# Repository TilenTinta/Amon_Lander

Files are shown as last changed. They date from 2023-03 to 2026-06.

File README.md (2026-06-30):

# Amon Lander Project

**Project Status:** In Progress

**Short description:** An open‑source EDF‑hovering lander/hopper inspired by **Sprite** (BPS.space)

> Part of the Amon Lander project:
>
> - **Amon Board** — flight controller hardware & firmware  
>   https://github.com/TilenTinta/Amon_Board
> - **Amon Link** — PC - drone RF bridge (PCB & firmware)  
>   https://github.com/TilenTinta/Amon_Link
> - **Amon Ground Control** — desktop GCS for telemetry & control  
>   https://github.com/TilenTinta/Amon_GroundControl_Software

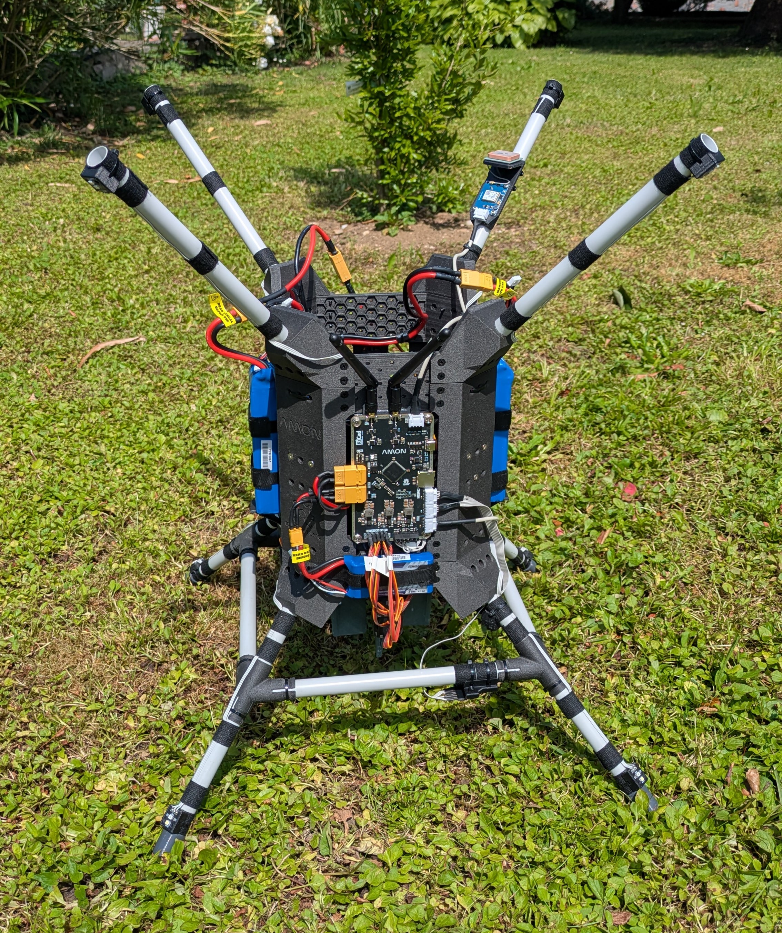
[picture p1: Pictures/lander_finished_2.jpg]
Amon Lander


---

## Table of Contents

- [Overview](#overview)
- [System Concept](#system-concept)
- [Hardware](#hardware)
  - [Frame](#frame)
  - [LED Boards](#led-boards)
- [Getting Started](#getting-started)
  - [Print & Materials](#print--materials)
  - [Assembly Notes](#assembly-notes)
- [Calibration & Testing](#calibration--testing)
- [Repository Structure](#repository-structure)
- [Roadmap](#roadmap)
- [Status & Disclaimer](#status--disclaimer)
- [License](#license)
- [Acknowledgments](#acknowledgments)

---

## Overview

Amon Lander is an educational lander/hopper platform designed to demonstrate vertical takeoff/landing and attitude control with thrust‑vectoring fins. The project emphasizes **building everything from scratch** and using mostly **free maker‑friendly tools**.

> [!INFO]
> **First integrated flight test:** 30.06.2026
>
> The goal of this flight was to validate the complete system, including the airframe, electronics, communications, protocol, flight controller, and ground station and have some fun!

---

## System Concept

- **Propulsion:** Single **EDF fan** for hover.  
- **Control:** **Four servos** drives fins for stabilization (**TVC**).  
- **Sensing:** Onboard sensors monitor flight parameters.  
- **Flight Computer:** **Custom PCB** handles computation and comms with the ground computer.  
- **Ground Segment:** Desktop app for **monitoring and control**.

> The goal is to learn: electronics, 3D modeling, embedded/desktop software, reading documentation, flight mechanics, and control theory—while having fun. Many things could be done faster or simpler, but this project idea is learning and exploration.

---

## Hardware

### Frame

The frame is inspired by Sprite, with custom ideas and modifications. The entire airframe is provided in **STL** and **STEP** and is printable on a standard **FDM** printer.  
- Early prototypes used **XPETG**; later versions used **LW‑PLA** to reduce weight.  
- Frame on image is **not yet flight‑tested** (at least not autonomous flight).  
- Designed in **Autodesk Fusion 360 (Personal Use license)**.

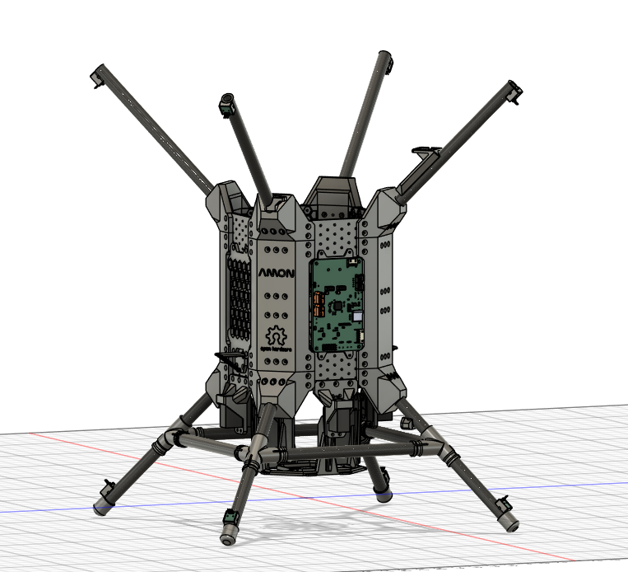
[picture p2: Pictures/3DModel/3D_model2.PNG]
3D Model


### LED Boards

Compact PCBs with two LEDs (**red** and **white**) indicate system state. They are mounted on the leg ends and top tubes. Although each LED board has a screw hole, **adhesive is recommended** for attachment.

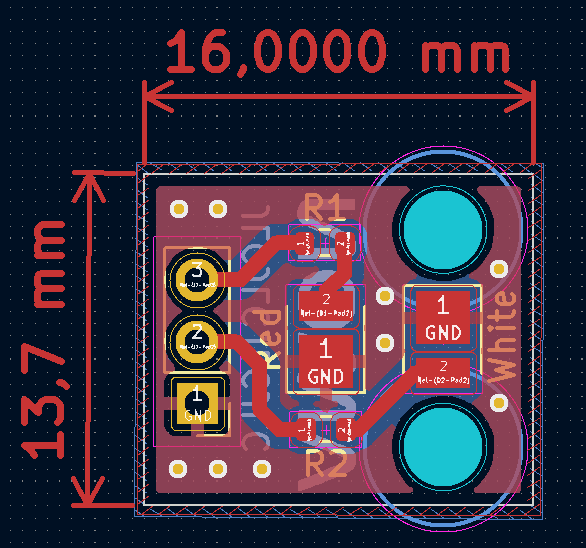
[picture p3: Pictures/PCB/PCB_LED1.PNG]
LED PCB


---

## Getting Started

### Print & Materials

- Slice **STL** parts per your printer’s capabilities.  
- Recommended filaments:
  - **LW‑PLA** (weight savings) or **PETG/XPETG** (durability).  
- Orient parts to maximize strength along load paths (legs, fins, mounts).

### Assembly Notes

- Dry‑fit major components before final fastening/adhesive.  
- Verify servo travel and linkage geometry with power **off** first.  
- Route wiring to avoid EDF ingestion and moving fin linkages.  

---

## Calibration & Testing

- Bench‑test **sensors** and **servo directions** before powering the EDF.  
- Perform staged tests: electronics bring‑up → servo only → tethered hover.  
- Log telemetry and review for oscillations; tune control gains incrementally.  

### Test stand
For each test there is a separate test stand. There are:
- Thrust stand (test of EDF thrust level)
- Servo stand (test of servo rotation)
- One and two DoF stand (test of drone moments and fin deflection effect)

All tests are done with the help of an Arduino Uno board used for collecting data from sensors. At the same time, a connection over UART-USB is established to a drone for direct communication and command transmission. Everything is monitored by Jupyter scripts for easy and quick tests. Results are saved in **.csv** files for easy future analysis.

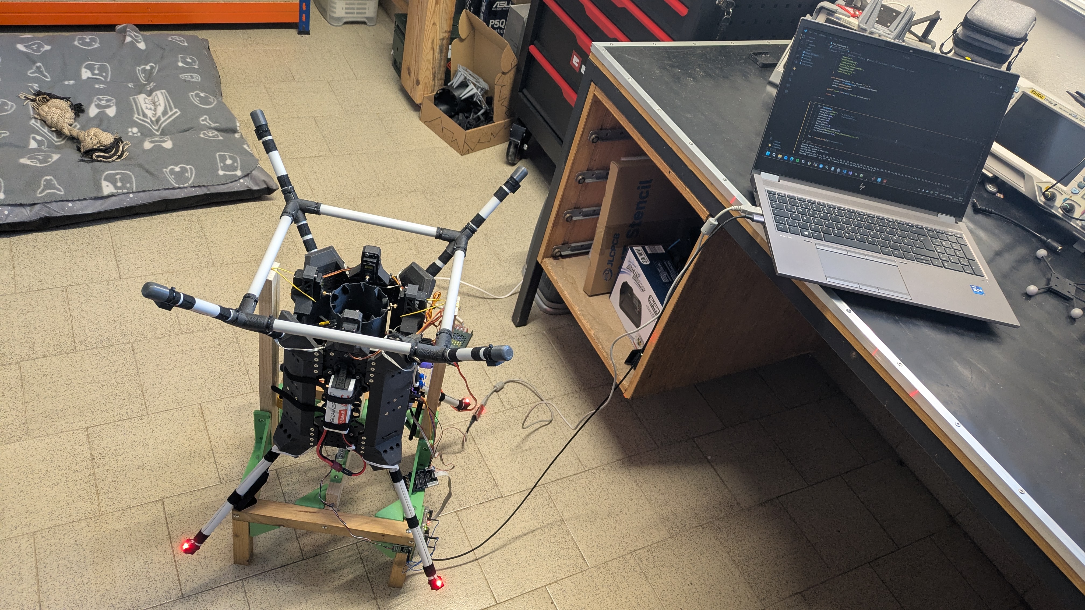
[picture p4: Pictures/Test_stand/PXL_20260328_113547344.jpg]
TEST STAND


---

## Control algorithm
The initial plan was to use **Matlab** with **Simulink** to create a complete mathematical model of the drone. After further research, I found that many different methods could be used for controlling a drone like this. After designing the first model in **Simulink** and experimenting with the **Simulink Coder** plugin — with the idea of converting it to standard C code for use on my flight controller — I abandoned this approach. The complete model was then rewritten in **Python** using the **NumPy** library, which is used to test, tune, and further refine the drone model. This same model was subsequently rewritten in **CasADi** style, inheriting the **NumPy** parameters. It is still used in Python, but now with the **acados** framework and optimizer to export the complete control code directly to my MCU/flight controller.

Links to libraries:
- **CasADi**: https://github.com/casadi/casadi
- **acados**: https://github.com/acados/acados

---

## Status & Disclaimer

**In active development.** Designs and documents are evolving; expect changes and rough edges. Exercise caution when testing EDF propulsion and keep bystanders at a safe distance.

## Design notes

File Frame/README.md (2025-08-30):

Amon Lander - Frame

The enire frame was inspired by BPS sprite drone but with my ideas and modifications. Entire drone is available is STL and STEP file format and can be 3D printed on clasic FDM 3D printer. For the first version of drone i used XPETG but then i switched to LW-PLA to decrease the weight. None on the frames was not been tested in air to that moments.
Everything was designed in Autodesk Fusion 360 (Hobbyist/Personal Use licence)



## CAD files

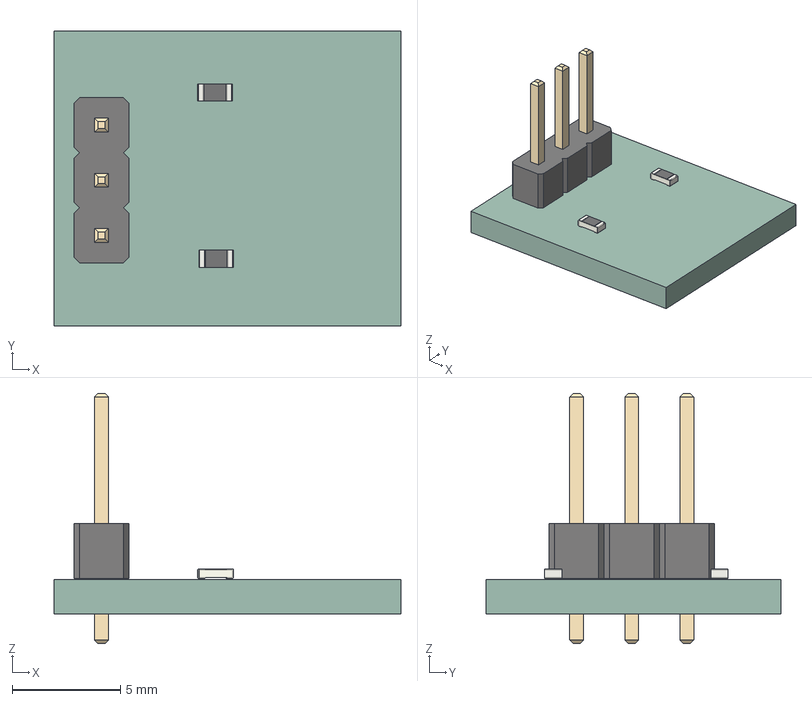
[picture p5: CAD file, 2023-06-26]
Amon_led_board/Amon_led_board.step
16.0 x 13.6 x 11.5 mm
PCB

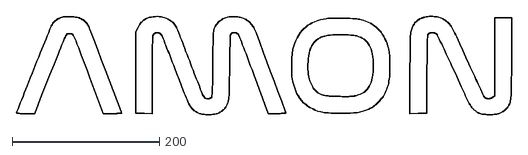
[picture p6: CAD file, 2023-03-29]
Data/Logo/AMON_logo.dxf
672.8 x 133.6

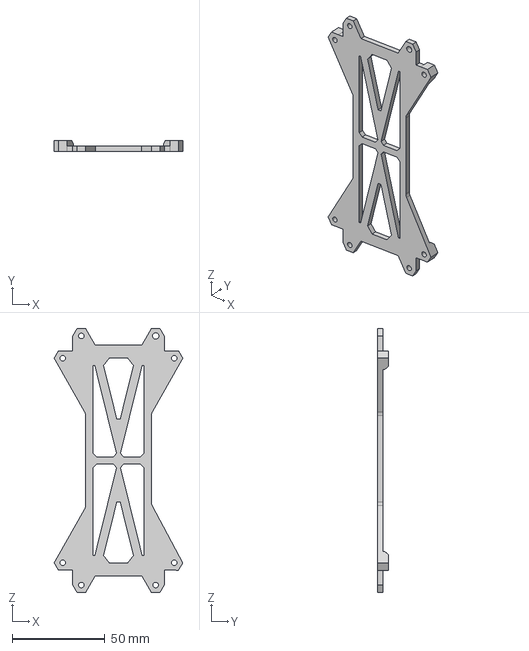
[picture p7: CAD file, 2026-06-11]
Frame/STEP/Amon_Board_holder v9.step
69.2 x 6.00 x 142.0 mm

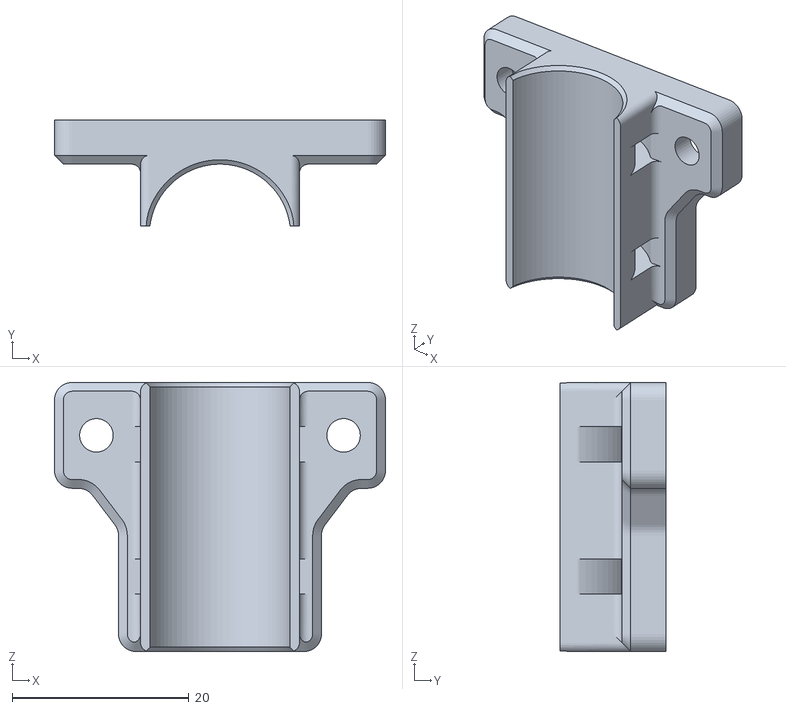
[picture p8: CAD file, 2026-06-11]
Frame/STL/TOF_mount v2.stl
37.5 x 12.0 x 30.5

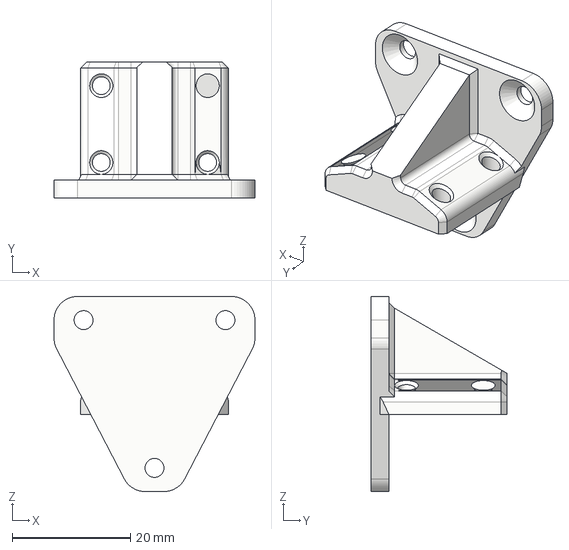
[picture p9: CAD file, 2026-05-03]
Test_stand/Moment_test/Frame/STEP/Gimbal_mount-drone_tab.step
34.0 x 23.0 x 33.0 mm

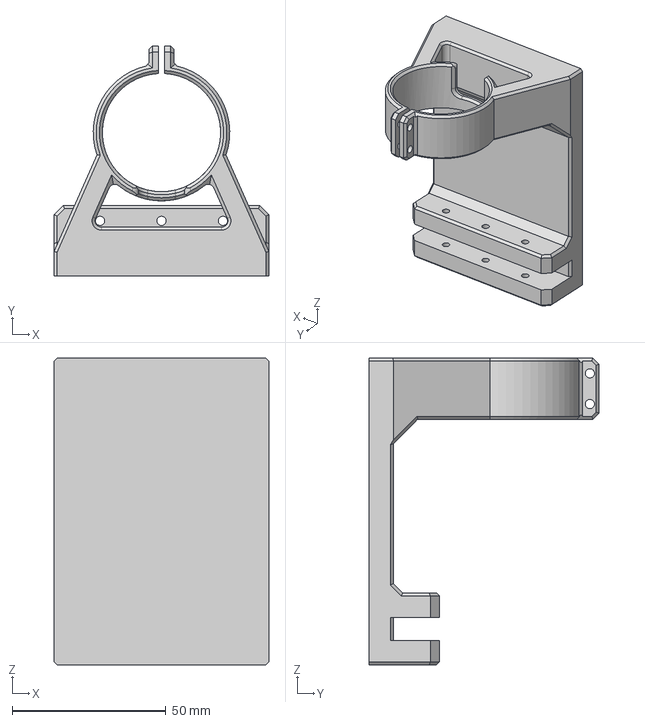
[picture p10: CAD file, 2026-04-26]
Test_stand/Servo_test/Frame/STEP/Base_encoder.step
70.0 x 75.0 x 100.0 mm

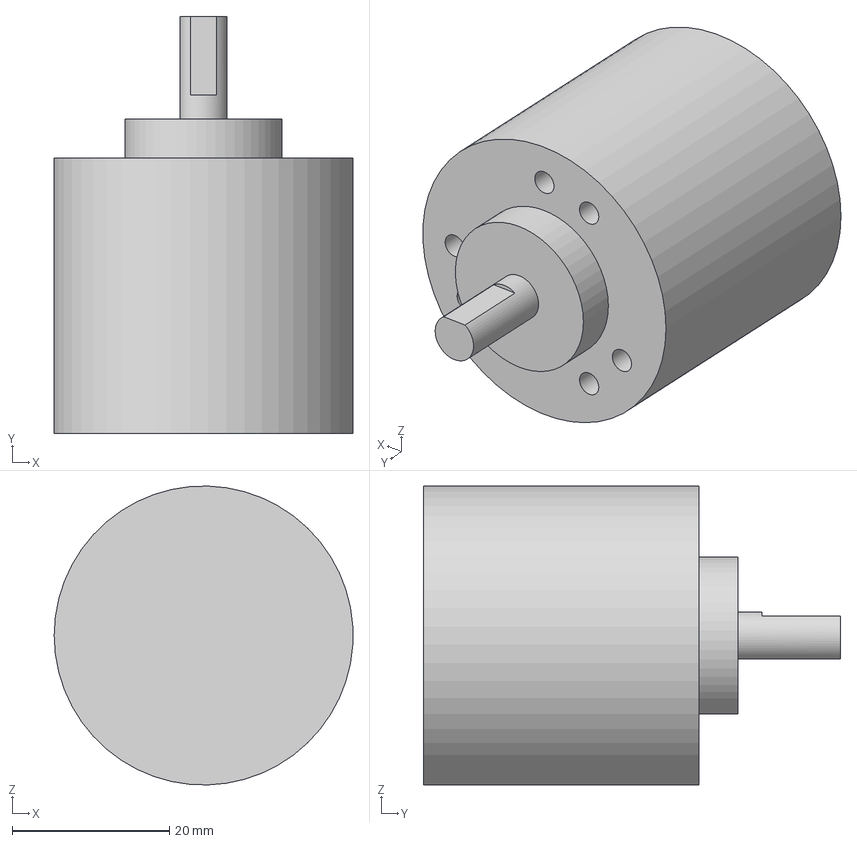
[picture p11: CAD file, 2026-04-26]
Test_stand/Thrust_test/Frame/STEP/e38s6g5 600b g24n.step
38.0 x 53.0 x 38.0 mm

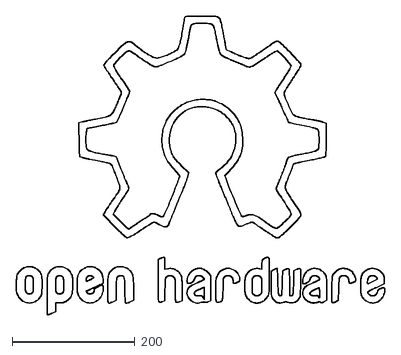
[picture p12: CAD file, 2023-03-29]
Data/Logo/NicePng_raspberry-pi-logo-png_1984009.dxf
600.0 x 486.7

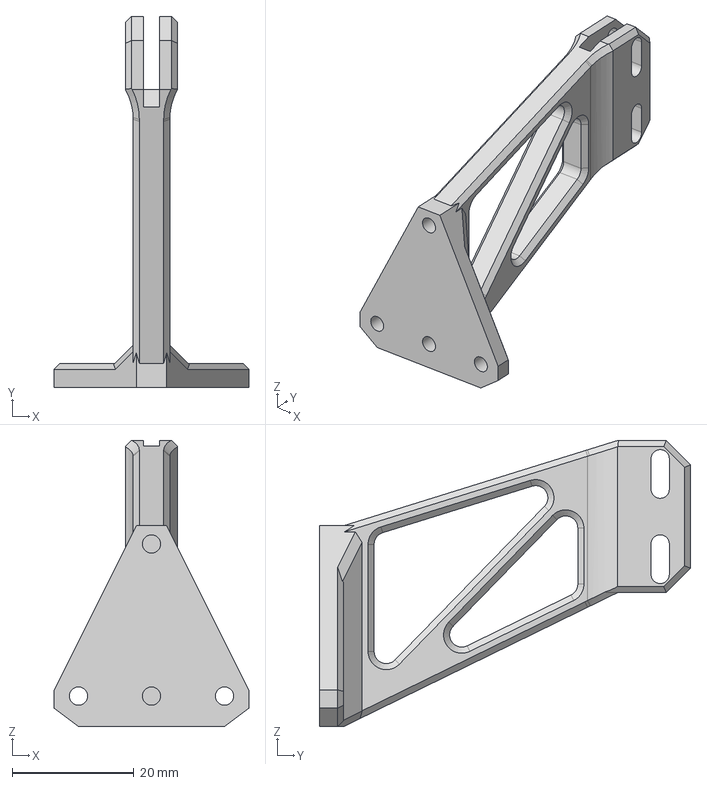
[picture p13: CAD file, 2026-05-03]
Frame/STEP/EDF_mount_80mm.step
32.0 x 61.0 x 47.0 mm

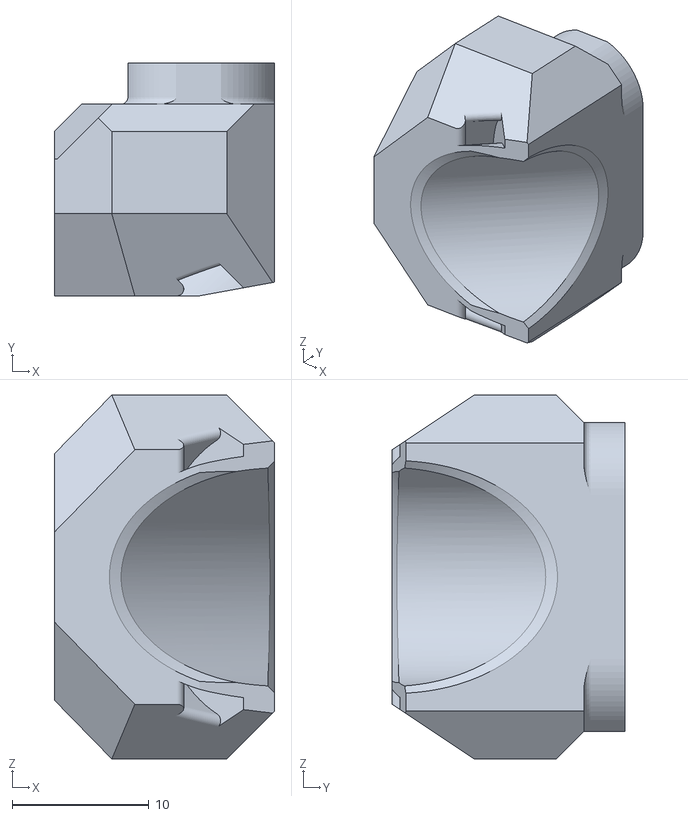
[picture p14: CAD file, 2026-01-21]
Frame/STL/Lidar_mount v7.stl
16.1 x 17.0 x 26.6

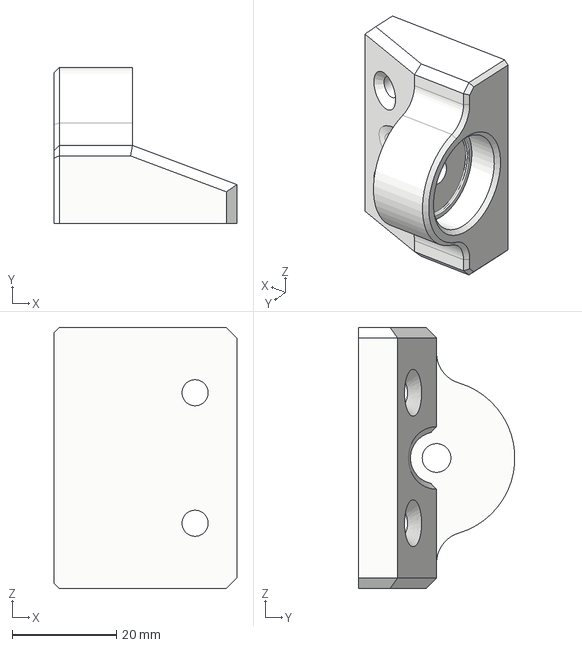
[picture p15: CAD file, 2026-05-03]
Test_stand/Moment_test/Frame/STEP/Gimbal_mount-base.step
35.0 x 30.0 x 50.0 mm

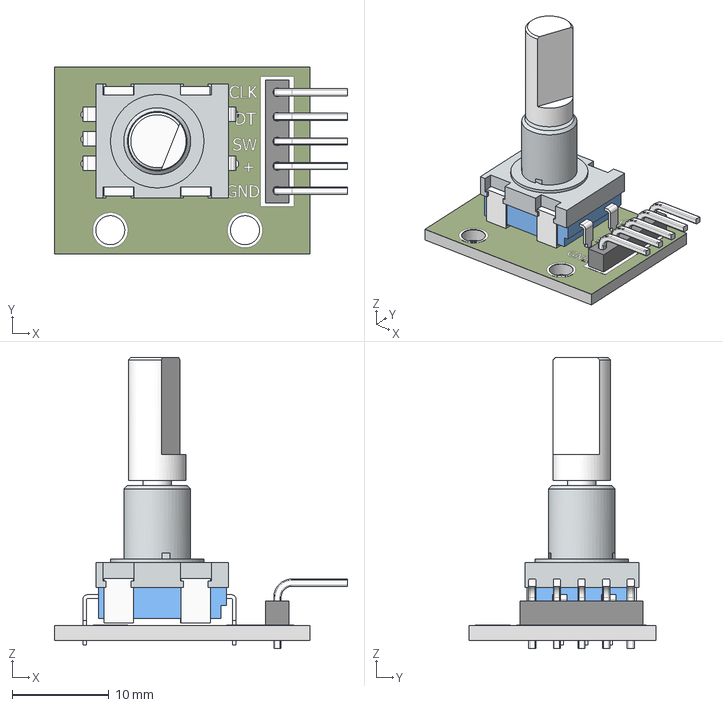
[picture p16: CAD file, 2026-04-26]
Test_stand/Thrust_test/Frame/STEP/rotary encoder_chesr_2013.stp
30.3 x 19.3 x 30.1 mm

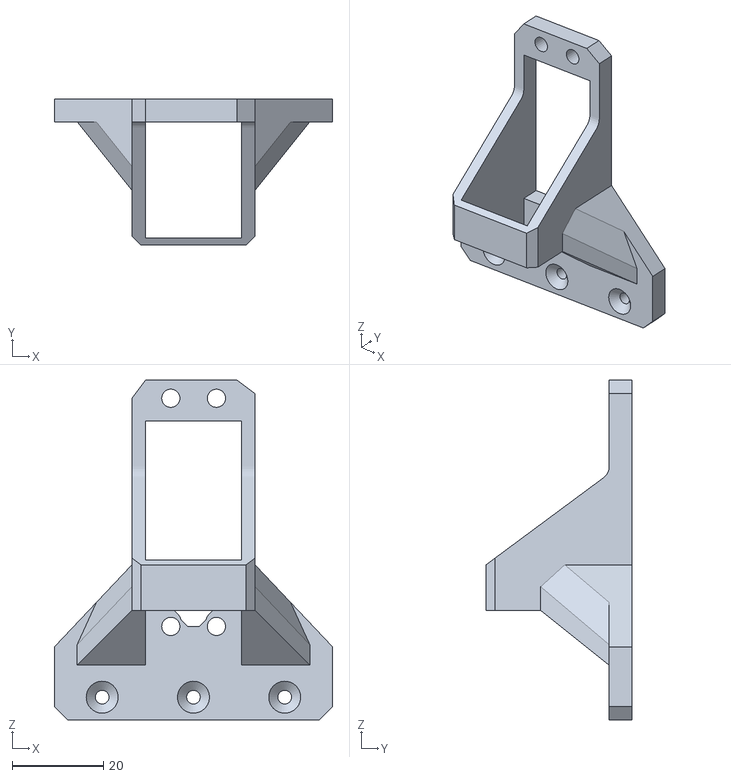
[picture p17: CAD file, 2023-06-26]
Frame/STL/Servo_holder_180mm v17.stl
61.0 x 32.0 x 74.5

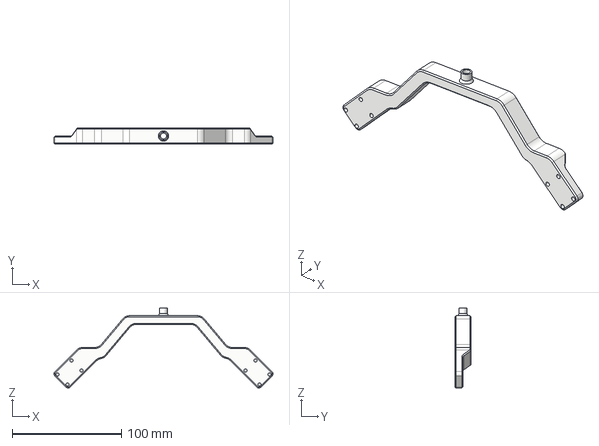
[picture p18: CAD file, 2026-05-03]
Test_stand/Moment_test/Frame/STEP/Gimbal_mount-side_bar_1.step
200.4 x 15.0 x 73.1 mm

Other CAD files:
Test_stand/Thrust_test/Frame/STEP/Load_cell_mount.step
Frame/STEP/Fin_stabilizer_servoInside v8.step
Frame/STL/EDF_mount_80mm v3.stl
Test_stand/Moment_test/Frame/STEP/Slider_1.step
Frame/STEP/Antena_holder v3.step
Frame/STEP/Base_frame_180mm v14.step
Frame/STEP/Battery_holder v10.step
Frame/STEP/Battery_holder_pcb v3.step
Frame/STEP/Battery_support v7.step
Frame/STEP/EDF_Duct v11.step
Frame/STEP/EDF_mount_80mm-stabilizer v8.step
Frame/STEP/ESC_holder v7.step
Frame/STEP/Fin v10.step
Frame/STEP/Fin_stabilizer_servoInside v2.step
Frame/STEP/GPS_holder v4.step
Frame/STEP/Handle.step
Frame/STEP/Leg_connector v22.step
Frame/STEP/Leg_holder v16.step
Frame/STEP/Legs_leds_holder v2.step
Frame/STEP/Lidar_mount v6.step
Frame/STEP/OptiTrack_marker_mount v3.step
Frame/STEP/Radio_stabilizer v6.step
Frame/STEP/Rubber_feet v4.step
Frame/STEP/Servo_holder_180mm v12.step
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

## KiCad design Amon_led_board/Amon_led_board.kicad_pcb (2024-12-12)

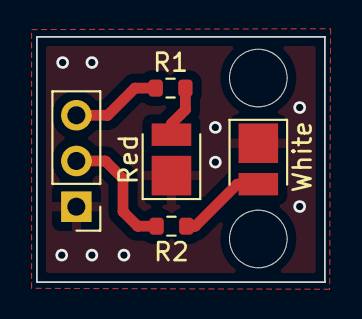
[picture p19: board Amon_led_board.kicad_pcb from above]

Board: 2 copper layers, 16.0 x 13.6 mm, 5 parts (0 on the bottom side), 5 nets.

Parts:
J1: 3_Pin_Male; PinHeader_1x03_P2.54mm_Vertical
R1, R2: 40 Ohm; R_0603_1608Metric
Red: RED; LED_PLCC_2835
White: WHITE; LED_PLCC_2835

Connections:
GND: J1.1, Red.1 (K), White.1 (K)
unnamed: R1.2, Red.2 (A)
unnamed: R2.2, White.2 (A)
unnamed: J1.2, R2.1
unnamed: J1.3, R1.1

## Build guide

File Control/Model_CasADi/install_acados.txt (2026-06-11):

### How to install acados library - required linux/WSL ###
# 1) Clone repository
git clone https://github.com/acados/acados.git
cd acados
git submodule update --recursive --init

# 2) Build library
mkdir build
cd build
cmake ..
make install -j4

# 3) Install library
cd ..
pip install -e interfaces/acados_template

# 4) Set enviroment variables
export LD_LIBRARY_PATH=$LD_LIBRARY_PATH:$HOME/acados/lib
export ACADOS_SOURCE_DIR=$HOME/acados

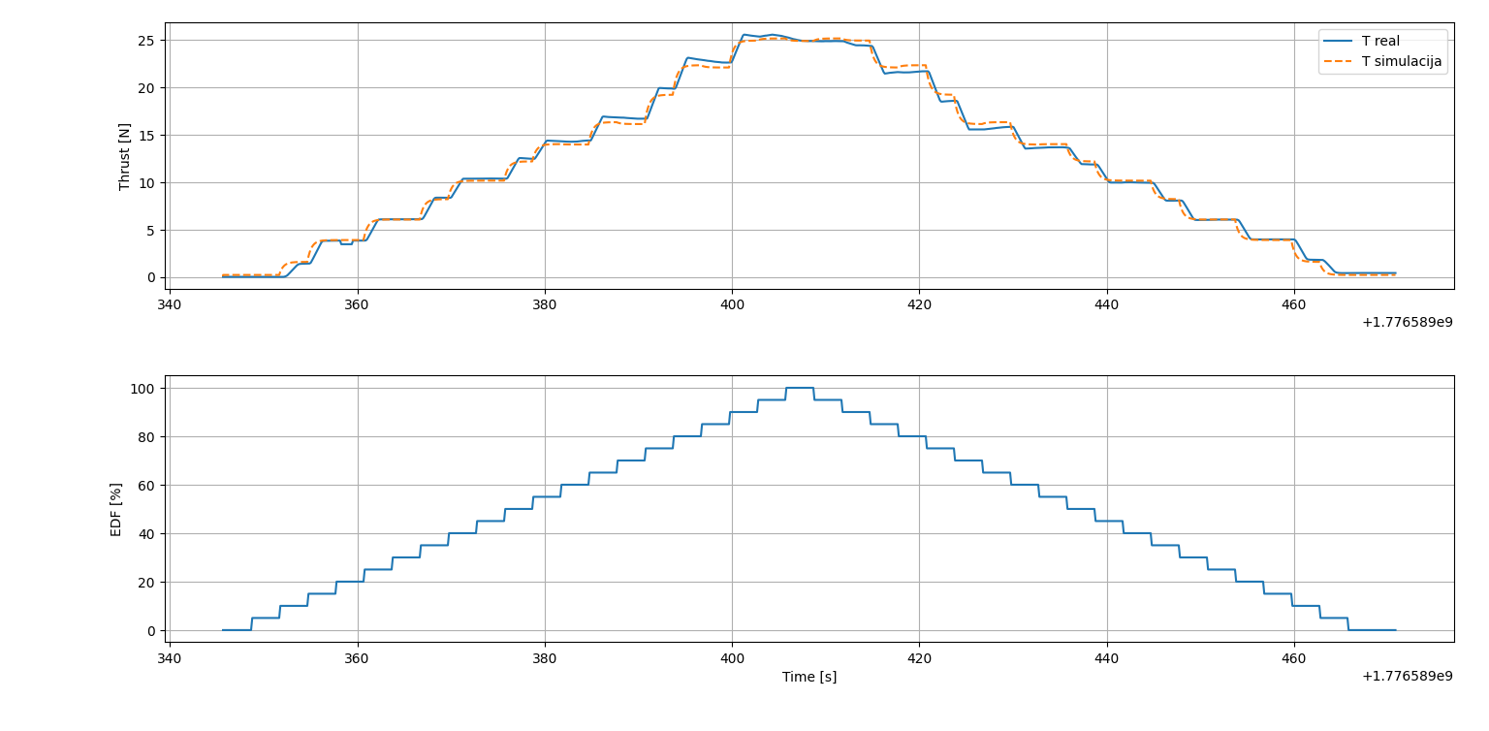
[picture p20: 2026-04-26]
Control/Model_CasADi/amon/resoults/thrust_0-100-0_step5_20260419_1.png

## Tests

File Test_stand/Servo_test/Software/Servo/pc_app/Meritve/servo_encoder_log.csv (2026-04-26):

pc_time_s | arduino_time_us | step_index | step_direction | servo_channel | commanded_angle_deg | encoder_count_raw | encoder_count_moving_avg | encoder_angle_deg | encoder_counts_per_rev | moving_avg_window_samples | transition_flag | time_since_step_s | sent_frame_hex
1776965085.95875 | 1391703301 | 0 | hold | y_plus | 0 | 0 | 0.0 | 0.0 | 1000 | 5 | 1 | 0.0004563331604003906 | aa 0d 01 05 01 20 60 05 00 5a 5a 5a 5a 7a b6
1776965085.958869 | 1391723306 | 0 | hold | y_plus | 0 | 0 | 0.0 | 0.0 | 1000 | 5 | 0 | 0.0005753040313720703 | aa 0d 01 05 01 20 60 05 00 5a 5a 5a 5a 7a b6
1776965085.9589787 | 1391743306 | 0 | hold | y_plus | 0 | 0 | 0.0 | 0.0 | 1000 | 5 | 0 | 0.0006849765777587891 | aa 0d 01 05 01 20 60 05 00 5a 5a 5a 5a 7a b6
1776965085.9590836 | 1391763308 | 0 | hold | y_plus | 0 | 0 | 0.0 | 0.0 | 1000 | 5 | 0 | 0.0007898807525634766 | aa 0d 01 05 01 20 60 05 00 5a 5a 5a 5a 7a b6
1776965085.9591885 | 1391783309 | 0 | hold | y_plus | 0 | 0 | 0.0 | 0.0 | 1000 | 5 | 0 | 0.0008947849273681641 | aa 0d 01 05 01 20 60 05 00 5a 5a 5a 5a 7a b6
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

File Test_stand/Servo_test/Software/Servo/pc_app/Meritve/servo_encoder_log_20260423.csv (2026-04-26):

pc_time_s | arduino_time_us | step_index | step_direction | servo_channel | commanded_angle_deg | encoder_count_raw | encoder_count_moving_avg | encoder_angle_deg | encoder_counts_per_rev | moving_avg_window_samples | transition_flag | time_since_step_s | sent_frame_hex
1776963994.8157945 | 300554972 | 0 | hold | y_plus | 0 | 0 | 0.0 | 0.0 | 1000 | 5 | 1 | -7.05718994140625e-05 | aa 0d 01 05 01 20 60 05 00 5a 5a 5a 5a 7a b6
1776963994.8160548 | 300574975 | 0 | hold | y_plus | 0 | 0 | 0.0 | 0.0 | 1000 | 5 | 0 | 0.00018978118896484375 | aa 0d 01 05 01 20 60 05 00 5a 5a 5a 5a 7a b6
1776963994.8161619 | 300594981 | 0 | hold | y_plus | 0 | 0 | 0.0 | 0.0 | 1000 | 5 | 0 | 0.0002968311309814453 | aa 0d 01 05 01 20 60 05 00 5a 5a 5a 5a 7a b6
1776963994.816266 | 300614986 | 0 | hold | y_plus | 0 | 0 | 0.0 | 0.0 | 1000 | 5 | 0 | 0.0004010200500488281 | aa 0d 01 05 01 20 60 05 00 5a 5a 5a 5a 7a b6
1776963994.8163643 | 300634990 | 0 | hold | y_plus | 0 | 0 | 0.0 | 0.0 | 1000 | 5 | 0 | 0.0004992485046386719 | aa 0d 01 05 01 20 60 05 00 5a 5a 5a 5a 7a b6
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

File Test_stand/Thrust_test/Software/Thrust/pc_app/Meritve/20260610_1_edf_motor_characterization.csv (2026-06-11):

pc_time_s | arduino_time_us | step_index | step_direction | edf_power_percent | load1_raw | load2_raw | load1_moving_avg | load2_moving_avg | moving_avg_window_samples | transition_flag | time_since_step_s | sent_frame_hex
1781108043.7030437 | 7944312 | 0 | up | 0 | 0.0 | 0.0 | 0.0 | 0.0 | 10 | 1 | 0.0013208389282226562 | aa 0d 01 05 01 20 60 05 00 5a 5a 5a 5a 7a b6
1781108043.7037024 | 8069316 | 0 | up | 0 | -59.0 | 0.0 | -29.5 | 0.0 | 10 | 0 | 0.0019795894622802734 | aa 0d 01 05 01 20 60 05 00 5a 5a 5a 5a 7a b6
1781108043.7043374 | 8194316 | 0 | up | 0 | -70.0 | 0.0 | -43.0 | 0.0 | 10 | 0 | 0.0026144981384277344 | aa 0d 01 05 01 20 60 05 00 5a 5a 5a 5a 7a b6
1781108043.7055216 | 8319316 | 0 | up | 0 | -13.0 | 0.0 | -35.5 | 0.0 | 10 | 0 | 0.0037987232208251953 | aa 0d 01 05 01 20 60 05 00 5a 5a 5a 5a 7a b6
1781108043.7062585 | 8444316 | 0 | up | 0 | 8.0 | 0.0 | -26.8 | 0.0 | 10 | 0 | 0.004535675048828125 | aa 0d 01 05 01 20 60 05 00 5a 5a 5a 5a 7a b6
1781108043.7073455 | 8569316 | 0 | up | 0 | 50.0 | 0.0 | -14.0 | 0.0 | 10 | 0 | 0.0056226253509521484 | aa 0d 01 05 01 20 60 05 00 5a 5a 5a 5a 7a b6
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

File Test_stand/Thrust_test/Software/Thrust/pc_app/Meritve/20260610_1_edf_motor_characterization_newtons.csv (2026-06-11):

pc_time_s | arduino_time_us | step_index | step_direction | edf_power_percent | load1_raw | load2_raw | load1_moving_avg | load2_moving_avg | moving_avg_window_samples | transition_flag | time_since_step_s | sent_frame_hex | calibration_mass_g | cal_zero_counts_loadcell1 | cal_loaded_counts_loadcell1 | delta_counts_loadcell1 | counts_per_kg_loadcell1 | counts_per_kg_loadcell2 | force1_N | force2_N | force_total_N_tared | scale_force_total_N | tare_mass_g | tare_force_N | thrust_N
1781108043.7030437 | 7944312 | 0 | up | 0 | 0.0 | 0.0 | 0.0 | 0.0 | 10 | 1 | 0.0013208389282226 | aa 0d 01 05 01 20 60 05 00 5a 5a 5a 5a 7a b6 | 1000.0 | 14700 | 228650 | 213950 | 213950.0 | 213950.0 | 0.0 | 0.0 | 0.0 | 24.3989452 | 2488 | 24.3989452 | 0.0
1781108043.7037024 | 8069316 | 0 | up | 0 | -59.0 | 0.0 | -29.5 | 0.0 | 10 | 0 | 0.0019795894622802 | aa 0d 01 05 01 20 60 05 00 5a 5a 5a 5a 7a b6 | 1000.0 | 14700 | 228650 | 213950 | 213950.0 | 213950.0 | -0.0013521672119654125 | 0.0 | -0.0013521672119654125 | 24.397593032788034 | 2488 | 24.3989452 | -0.0013521672119654125
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

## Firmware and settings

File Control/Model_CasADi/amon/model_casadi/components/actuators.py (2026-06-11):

from casadi import *
from model_casadi.math.math import saturate, lookup_1d, deg_to_rad


def edf_block_instant(edf_cmd, params):
    """
    EDF brez dinamike (instant)
    """

    # --------------------------------------------------------
    # Saturacija
    # --------------------------------------------------------
    edf_cmd = saturate(edf_cmd, params.actuator.edf_min, params.actuator.edf_max)

    # --------------------------------------------------------
    # Lookup
    # --------------------------------------------------------
    T_cmd = lookup_1d(edf_cmd, params.thrust.edf_table, params.thrust.thrust_table)

    return T_cmd



def edf_block_1st_order(T, edf_cmd, params):
    """
    CasADi EDF model (1. red)
    """

    # --------------------------------------------------------
    # Saturacija
    # --------------------------------------------------------
    edf_cmd = saturate(edf_cmd, params.actuator.edf_min, params.actuator.edf_max)

    # --------------------------------------------------------
    # Lookup
    # --------------------------------------------------------
    T_cmd = lookup_1d(edf_cmd, params.thrust.edf_table, params.thrust.thrust_table)

    # --------------------------------------------------------
    # Dinamika 1. reda
    # --------------------------------------------------------
    tau_up = params.actuator.tau_edf_up
    tau_down = params.actuator.tau_edf_down
    tau = if_else(T_cmd > T, tau_up, tau_down)
    dT = (T_cmd - T) / tau

    return dT, T_cmd



def edf_block_2nd_order(T, T_dot, edf_cmd, params):
    """
    CasADi EDF model (2. red)
    """

    # --------------------------------------------------------
    # Saturacija
    # --------------------------------------------------------
    edf_cmd = saturate(edf_cmd, params.actuator.edf_min, params.actuator.edf_max)

    # --------------------------------------------------------
    # Lookup
    # --------------------------------------------------------
    T_cmd = lookup_1d(edf_cmd, params.thrust.edf_table, params.thrust.thrust_table)

    # --------------------------------------------------------
    # Parametri (up/down)
    # --------------------------------------------------------
    wn_up = params.actuator.wn_up_edf
    zeta_up = params.actuator.zeta_up_edf

    wn_down = params.actuator.wn_down_edf
    zeta_down = params.actuator.zeta_down_edf

    wn = if_else(T_cmd > T, wn_up, wn_down)
    zeta = if_else(T_cmd > T, zeta_up, zeta_down)

    # --------------------------------------------------------
    # Dinamika 2. reda
    # --------------------------------------------------------
    dT = T_dot

    dT_dot = wn**2 * (T_cmd - T) - 2 * zeta * wn * T_dot

    return dT, dT_dot, T_cmd



def servo_block_instant(servo_cmd_deg, params, servo_offset_rad=0.0):
    """
    Servo brez dinamike
    """

    # --------------------------------------------------------
    # Saturacija
    # --------------------------------------------------------
    servo_cmd_deg = saturate(servo_cmd_deg, params.actuator.servo_min, params.actuator.servo_max)

    # --------------------------------------------------------
    # Deg -> rad + offset
    # --------------------------------------------------------
    delta_cmd = deg_to_rad(servo_cmd_deg) + servo_offset_rad

    return delta_cmd



def servo_block_1st_order(delta, servo_cmd_deg, params, servo_offset_rad=0.0):
    """
    CasADi servo model (1. red)
    """

    # --------------------------------------------------------
    # Saturacija
    # --------------------------------------------------------
    servo_cmd_deg = saturate(servo_cmd_deg, params.actuator.servo_min, params.actuator.servo_max)

    # --------------------------------------------------------
    # Deg -> rad + offset
    # --------------------------------------------------------
    delta_cmd = deg_to_rad(servo_cmd_deg) + servo_offset_rad

    # --------------------------------------------------------
    # Dinamika 1. reda
    # --------------------------------------------------------
    tau = params.actuator.tau_servo
    ddelta = (delta_cmd - delta) / tau

    return ddelta, delta_cmd



def servo_block_2nd_order(delta, delta_dot, servo_cmd_deg, params, servo_offset_rad=0.0):
    """
    CasADi servo model (2. red, brez delay)
    """

    # --------------------------------------------------------
    # Saturacija
    # --------------------------------------------------------
    servo_cmd_deg = saturate(servo_cmd_deg, params.actuator.servo_min, params.actuator.servo_max)

    # --------------------------------------------------------
    # Deg -> rad + offset
    # --------------------------------------------------------
    delta_cmd = deg_to_rad(servo_cmd_deg) + servo_offset_rad

    # --------------------------------------------------------
    # Parametri (up/down)
    # --------------------------------------------------------
    wn_up = params.actuator.wn_up_servo
    zeta_up = params.actuator.zeta_up_servo

    wn_down = params.actuator.wn_down_servo
    zeta_down = params.actuator.zeta_down_servo

    wn = if_else(delta_cmd > delta, wn_up, wn_down)
    zeta = if_else(delta_cmd > delta, zeta_up, zeta_down)

    # --------------------------------------------------------
    # Dinamika 2. reda
    # --------------------------------------------------------
    ddelta = delta_dot

    ddelta_dot = wn**2 * (delta_cmd - delta) - 2 * zeta * wn * delta_dot

    return ddelta, ddelta_dot, delta_cmd



def servo_block_4_instant(servo_cmd_deg, params):
    """
    4 servo modeli brez dinamike
    """

    delta_cmd = []

    offsets = params.actuator.delta_0

    for i in range(4):
        cmd = servo_block_instant(
            servo_cmd_deg[i],
            params,
            servo_offset_rad=offsets[i]
        )

        delta_cmd.append(cmd)

    return vertcat(*delta_cmd)



def servo_block_4_1st_order(delta, servo_cmd_deg, params):
    """
    4 servo modeli (1. red)
    """

    ddelta = []
    delta_cmd = []

    offsets = params.delta_0

    for i in range(4):
        d, cmd = servo_block_1st_order(
            delta[i],
            servo_cmd_deg[i],
            params,
            servo_offset_rad=offsets[i]
        )

        ddelta.append(d)
        delta_cmd.append(cmd)

    return vertcat(*ddelta), vertcat(*delta_cmd)
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

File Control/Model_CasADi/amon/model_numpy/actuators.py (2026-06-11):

"""
Amon Lander - Model aktuatorjev

"""

import numpy as np
from collections import deque


# ============================================================
# Saturacija
# ============================================================
def saturate(value, value_min, value_max):
    return np.clip(value, value_min, value_max)


# ============================================================
# FIFO zakasnitev / delay
# ============================================================
def delay_buffer(delay_s, dt, init_value=0.0):
    n = max(1, int(round(delay_s / dt)))
    return deque([init_value] * n, maxlen=n)


# ============================================================
# Stopinje -> radiani
# ============================================================
def deg_to_rad(angle_deg):
    return angle_deg * np.pi / 180.0


# ============================================================
# Lookup tabela - Linearna interpolacija
# ============================================================
def lookup_1d(x, x_table, y_table):
    """
    1D lookup (kot Simulink 1-D Lookup Table)
    """

    return np.interp(x, x_table, y_table)


# ============================================================
# EDF blok
# ============================================================
def edf_block(T, edf_cmd, params):
    """
    EDF blok

    Vhod:
    - T        : vzgon [N]
    - edf_cmd  : ukaz [%]

    Izhod:
    - T_dot
    - T_cmd
    """

    # Saturacija vhoda
    edf_cmd = saturate(edf_cmd, params.actuator.edf_min, params.actuator.edf_max)

    # Lookup tabela
    T_cmd = lookup_1d(edf_cmd, params.thrust.edf_table, params.thrust.thrust_table)

    # tau_edf_up in tau_edf_down sta lahko različna
    if T_cmd > T:
        tau = params.actuator.tau_edf_up
    else:
        tau = params.actuator.tau_edf_down

    # Dinamika 1. reda
    T_dot = (T_cmd - T) / tau

    # Dinamika 2. reda - mogoče???

    return T_dot, T_cmd



def edf_block_2nd_order(T, T_dot, edf_cmd, delay_buffer, params):
    """
    EDF blok - model 2. reda z zakasnitvijo

    Stanja:
    - T
    - T_dot

    Vhod:
    - edf_cmd [%]

    Izhodi:
    - dT
    - dT_dot
    - T_cmd
    - edf_cmd_delayed

    Warning:
        - Mogoče ga zamenjaj za instant kot ker drugače pri dt=0.01 in wn_up_edf > 1k dobiš nerešljivo optimizacijo
          Previsoka naravna frekvenca → stiff system → RK4 nestabilen → IPOPT ne konvergira
    """

    # Saturacija vhoda
    edf_cmd = saturate(edf_cmd, params.actuator.edf_min, params.actuator.edf_max)

    # FIFO zakasnitev
    edf_cmd_delayed = delay_buffer.popleft()
    delay_buffer.append(edf_cmd)
    
    # Lookup tabela
    T_cmd = lookup_1d(edf_cmd_delayed, params.thrust.edf_table, params.thrust.thrust_table)

    # Parametri gor / dol
    if T_cmd > T:
        w_n = params.actuator.wn_up_edf
        zeta = params.actuator.zeta_up_edf
    else:
        w_n = params.actuator.wn_down_edf
        zeta = params.actuator.zeta_down_edf

    # 2. red
    dT = T_dot
    dT_dot = w_n**2 * (T_cmd - T) - 2.0 * zeta * w_n * T_dot

    #print(f"cmd={edf_cmd:.1f}, delayed={edf_cmd_delayed:.1f}, T_cmd={T_cmd:.2f}")

    return dT, dT_dot, T_cmd, edf_cmd_delayed


# ============================================================
# Servo blok (en servo)
# ============================================================
def servo_block(delta, servo_cmd_deg, servo_offset_rad, params):
    """
    Servo blok

    Vhod:
    - delta           : kot [rad]
    - servo_cmd_deg   : ukaz [deg]
    - servo_offset_rad: offset [rad]

    Izhod:
    - delta_dot
    - delta_cmd_rad
    """

    # Saturacija v stopinjah
    servo_cmd_deg = saturate(servo_cmd_deg, params.actuator.servo_min, params.actuator.servo_max)

    # Pretvorba v radiane
    delta_cmd_rad = deg_to_rad(servo_cmd_deg)

    # Dodaj offset
    delta_cmd_rad = delta_cmd_rad + servo_offset_rad

    # Dinamika 1. reda
    delta_dot = (delta_cmd_rad - delta) / params.actuator.tau_servo

    return delta_dot, delta_cmd_rad


def servo_block_2nd_order(delta, delta_dot, servo_cmd_deg, delay_buffer, params, servo_offset_rad=0.0):
    """
    Servo blok - model 2. reda z zakasnitvijo

    Stanja:
    - delta
    - delta_dot

    Vhod:
    - servo_cmd_deg [deg]

    Izhod:
    - ddelta
    - ddelta_dot
    - delta_cmd_rad
    - servo_cmd_deg_delayed

    Warning:
        - Mogoče ga zamenjaj za instant kot ker drugače pri dt=0.01 in wn_up_servo > 1k rad/s dobiš nerešljivo optimizacijo
          Previsoka naravna frekvenca → stiff system → RK4 nestabilen → IPOPT ne konvergira    
    """

    # Saturacija v stopinjah
    servo_cmd_deg = saturate(servo_cmd_deg, params.actuator.servo_min, params.actuator.servo_max)

    # FIFO zakasnitev
    servo_cmd_deg_delayed = delay_buffer.popleft()
    delay_buffer.append(servo_cmd_deg)

    # Pretvorba v radiane (delayed)
    delta_cmd_rad = deg_to_rad(servo_cmd_deg_delayed) + servo_offset_rad

    # Parametri gor / dol
    if delta_cmd_rad > delta:
        w_n = params.actuator.wn_up_servo
        zeta = params.actuator.zeta_up_servo
    else:
        w_n = params.actuator.wn_down_servo
        zeta = params.actuator.zeta_down_servo

    # 2. red
    ddelta = delta_dot
    ddelta_dot = w_n**2 * (delta_cmd_rad - delta) - 2.0 * zeta * w_n * delta_dot

    return ddelta, ddelta_dot, delta_cmd_rad, servo_cmd_deg_delayed


# ============================================================
# 4 servo bloki
# ============================================================
def servo_block_4(delta, servo_cmd, params):
    """
    4 servo bloki

    Vhod:
    - delta      : trenutni koti [rad]
    - servo_cmd  : ukazi [deg]

    Izhod:
    - delta_dot
    - delta_cmd_rad
    """

    delta_dot = np.zeros(4)
    delta_cmd_rad = np.zeros(4)

    offsets = params.actuator.delta_0

    for i in range(4):
        delta_dot[i], delta_cmd_rad[i] = servo_block(delta[i], servo_cmd[i], offsets[i], params)

    return delta_dot, delta_cmd_rad
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

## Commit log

2022-12-04 Added Amon led board
    [Amon_led_board-B_Cu.gbr, Amon_led_board-B_Mask.gbr, Amon_led_board-B_Paste.gbr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]
2023-02-12 added Amon board and frame: both not last version
    [Amon_board.csv, Amon_board.kicad_pcb, Amon_board.kicad_sch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]
2023-03-14 PCB update, stl update (pcb holder)
    [Amon_board-B_Cu.gbl, Amon_board-B_Mask.gbs, Amon_board-B_Paste.gbp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]
2023-03-29 updated stl, data, board update
    [AMON_logo.dxf, Amon_Board_holder v7.stl, Amon_board.kicad_pcb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]
2023-04-08 PCB repair: crystal footprint, radio connector fliped, text
    [Amon_board.kicad_pcb, Amon_board.kicad_sch, power.kicad_sch]
2023-04-20 board firmware - BME280, LED..
2023-06-26 changed directories
    [Amon_Board_holder v8.stl, Amon_board.kicad_pcb, Amon_board.kicad_sch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]
2023-10-20 added pictires
    [Amon_board.kicad_pcb, Amon_board.kicad_sch, power.kicad_sch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]
2024-12-12 Update
    addes new images, filled and new READMEs, added pull-ups on PCB
    [Amon_Board_holder v7.stl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]
2025-08-30 Update
    project separation
    [Amon_board-B_Cu.gbl, Amon_board-B_Mask.gbs, Amon_board-B_Paste.gbp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]
2026-01-21 Update
    readme update
    [EDF_Duct v7.stl, EDF_mount_80mm-stabilizer v2.stl, EDF_mount_80mm-stabilizer v8.step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]
2026-02-23 Update
    stm and step files fot optitrack markers mount
    [Handle.step, Handle.stl, OptiTrack_marker_mount v3.step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]
2026-03-01 Update
    additional software
    [summary_20260301_114329.csv, summary_20260301_114358.csv, summary_20260301_114424.csv]
2026-03-01 Update
    Kalman calibration code and test
    [summary_20260301_114329.csv, summary_20260301_114358.csv, summary_20260301_114424.csv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]
2026-03-08 Update
    log parser and ploter
    [drone_log.csv, summary_20260301_151118.csv, summary_20260301_173029.csv]
2026-03-25 Update
    finished test stand (frame and software) but untested, start of control model
    [Angle_support.step, Angle_support.stl, Angle_support_big.step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]
2026-03-31 Update
    Matlab model in development
    [edf_motor_characterization.csv, edf_motor_characterization_20260328.csv, edf_motor_characterization_newtons.csv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]
2026-04-26 Update: model converted from Simulink to Python for easyer future use of acados library
    [Angle_support.step, Angle_support.stl, Angle_support_big.step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]
2026-05-03 Update: first test code for math model in casadi and acados
    [Amon_Board_holder v8.step, Angle_support.step, Angle_support.stl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]
2026-05-04 Update: casadi and acados model finished, problem with solver not converging (omega to big for dt)
    [parameters.py]
2026-05-06 Update: build of blasfeo and hpipm and recheck of casadi model, repair of gravity
    [edf_motor_characterization_20260418.csv, edf_motor_characterization_20260418_newtons.csv, edf_motor_characterization_20260419_1.csv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]
2026-06-11 Update: new file structure for nmpc, 50Hz to 100Hz, generated c code simulation
    [20260610_1_edf_motor_characterization.csv, 20260610_1_edf_motor_characterization_newtons.csv, Amon_Board_holder v8.step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]
